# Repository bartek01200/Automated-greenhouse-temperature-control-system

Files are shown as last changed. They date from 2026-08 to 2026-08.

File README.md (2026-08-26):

# Automated-greenhouse-temperature-control-system

An embedded greenhouse monitoring and ventilation system combining a custom PCB, BMP180 environmental sensor, embedded C++ firmware and servo-actuated window mechanism.

The system continuously monitors temperature and atmospheric pressure while allowing the user to set an adjustable 20–35°C temperature threshold using an onboard potentiometer.When the measured temperature exceeds the selected threshold,the controller automatically opens the ventilation window and activates visual and audible warning indicators.

### Front View
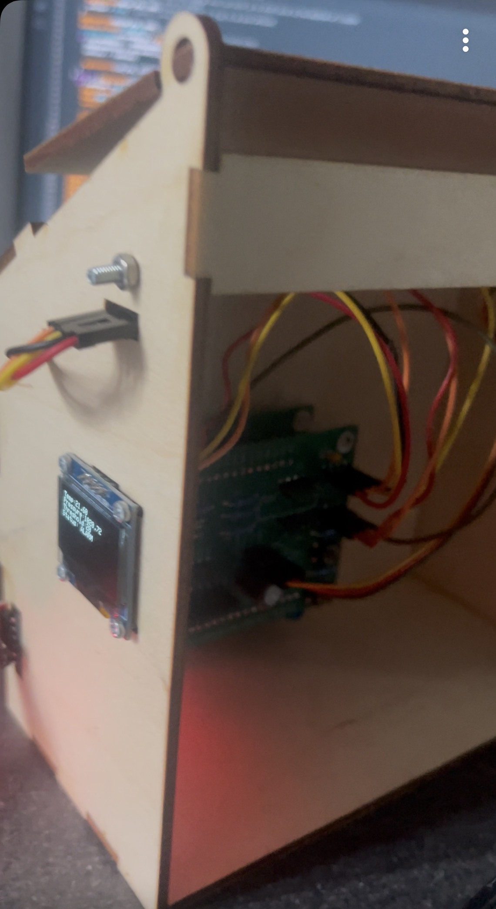
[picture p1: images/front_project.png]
Front Project View


### Side View
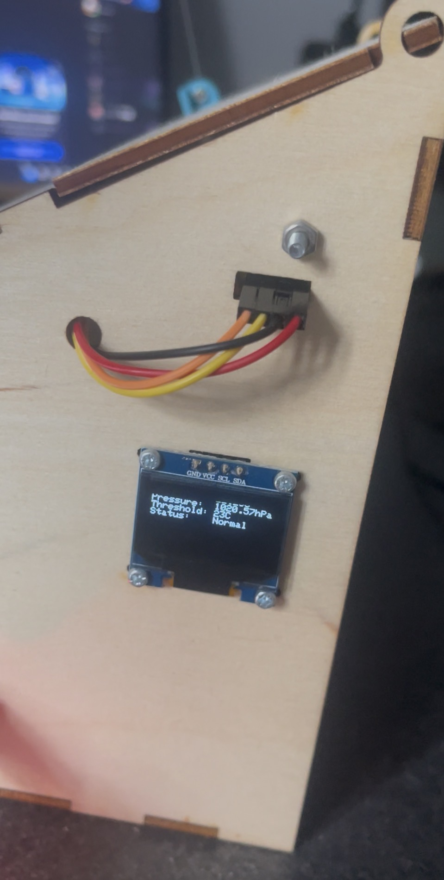
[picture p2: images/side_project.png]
Side View


## CAD Front view
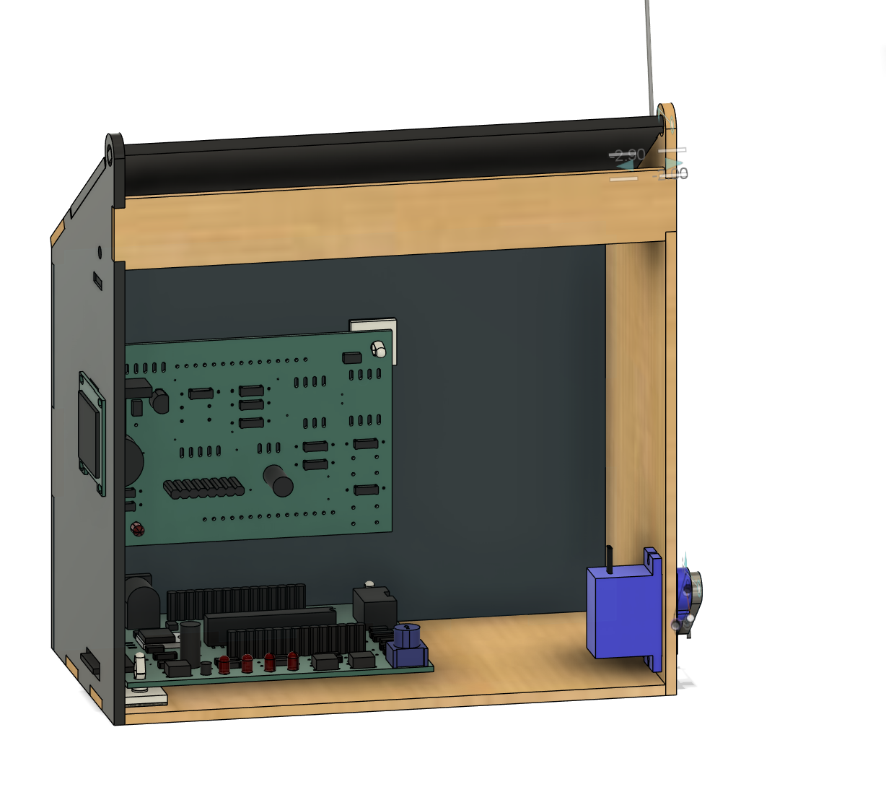
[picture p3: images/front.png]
Front View


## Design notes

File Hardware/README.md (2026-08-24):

## Hardware 

The project used a supplied TSC033 ATmega controller board. I assembled and soldered the controller board, programmed the MCU in C++ using the Arduino framework through the supplied USB programming adapter/interface PCB, and integrated the controller with my custom mating PCB and peripheral hardware.

The custom top board PCB, including the sensor interfaces, potentiometer input, relay driver, protection circuitry, servo interface and status outputs, was designed, assembled and soldered by me before being integrated with the firmware and mechanical system.

### Hardware features

- MCU mating headers for connection to the controller board

- BMP180 temperature and atmospheric pressure sensor interface

- SSD1306 OLED display interface over I²C

- nalogue potentiometer input for adjustable temperature threshold control

- Two push-button inputs for manual open and close override

- SG90 servo interface for ventilation control

- Relay controlled servo power switching

- 2N4401 NPN transistor relay driver

- 1N4004 flyback diode for inductive transient protection

- LED status indicators

- Audible buzzer output

- Local power-supply decoupling capacitors

- External relay output connection

- PCB mounting holes for mechanical integration

## Controller Platform
The system interfaces with a supplied **TSC033 ATmega-based controller board**, which provides the MCU, power regulation, programming interface and I/O connections used by the custom PCB.

The controller board was physically assembled and soldered by me as part of the project before integration with the custom top-board PCB.

Available MCU interfaces used by the system include:

- A0 –Potentiometer input for adjustable temperature threshold.
- A4 / SDA –I²C data connection.
- A5 / SCL –I²C clock connection.
  *Digital inputs -Manual control switches.
- Digital outputs –Status indicators, buzzer, relay and servo control.
- 5 V and GND rails –Power distribution to the custom PCB and peripherals.

The custom PCB was designed to mate with the controller board through the supplied board-to-board connector arrangement.

## Provided and Custom Hardware
Several components were supplied as part of the project platform, including:

- ATmega-based controller board
- I/O daughter board
- SG90 micro servo
- Greenhouse structural frame
- Push rod and associated hardware

These components were integrated with the electronics and mechanical system developed for the project.

My hardware work included:

- Designing the custom mating PCB.
- Designing the supporting sensor, actuator and user-interface circuitry.
- Implementing the relay driver and flyback protection circuit.
- Adding power-supply decoupling.
- Integrating the BMP180 and OLED through I²C.
- Integrating the potentiometer through the MCU ADC.
- Providing interfaces for the servo, buzzer, LEDs and manual controls.
- PCB assembly and soldering.
- System wiring, commissioning and debugging

### Relay Driver Circuit:

The relay is driven using a 2N4401 NPN transistor rather than directly from the MCU output.

The MCU controls the transistor through a base resistor, allowing the transistor to switch the higher relay coil current.

A 1N4004 flyback diode is connected across the relay coil to suppress the inductive voltage spike generated when the relay is switched off.

The relay is used to switch power to the servo motor during movement. Once the required window position has been reached, the firmware disables the relay to remove idle servo power and reduce unnecessary power consumption and servo jitter.

### Potentiometer Interface:

The potentiometer forms an analogue voltage divider between the supply and ground rails.

Its wiper is connected to the MCU's analogue input A0, allowing the firmware to sample its position using the ADC.

The resulting ADC value is mapped in firmware to an adjustable temperature threshold between:
20°C and 35°C

This provides real time hardware adjustment of the ventilation temperature without requiring firmware modification.

### PCB Layout:
The PCB layout integrates the MCU connectors and supporting circuitry onto a single board while providing connections for the sensor, display, servo and user controls.

During layout, component placement was arranged around the required MCU mating headers and mechanical constraints of the greenhouse assembly.

### PCB Assembly:
The PCB was manually assembled and soldered before system commissioning.

Following assembly, continuity and component connections were checked before the board was connected to the MCU and integrated with the complete system.

### Main Components:

- BMP180 - Temperature and atmospheric pressure sensing

- SSD1306 OLED - Real time system information display

- Potentiometer - User adjustable temperature threshold

- SG90 Servo - Greenhouse window actuation

- Relay - Servo power switching

- 2N4401- Relay driver transistor

- 1N4004- Relay flyback protection

- Push Buttons- Manual open/close override

- LEDs- Visual status indication

- Buzzer- Audible over temperature indication

- Decoupling Capacitors- Supply filtering and stability

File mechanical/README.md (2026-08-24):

## Mechanical 

The mechanical ssystem was designed in Autodesk Fusion 360 to support the  electronics and provide a servo actuated ventilation window.

The design integrates the window mechanism, SG90 servo motor which connects to metal rod, metal rod,roof mount,connector between rod and roof mount, environmental sensor and custom PCB into a complete electromechanical assembly.

## Mechanical Assembly
The greenhouse structure consists of several individual components assembled into the final enclosure and ventilation mechanism.

## CAD Design
Main mechanical components:
- Base plate
- Back panel
- Left and right side panels
- Front brace
- Fixed roof section
- Hinged ventilation roof/window
- SG90 servo mounting arrangement
- Push rod
- roof mount
- push rod connector
- Servo rotator/linkage
- PCB  standoff mounts 4x on each corner to help with cooling and preventing shorting
- Sensor mounting provision
- OLED mounting provision

The assembly was designed to support and integrate the custom PCB, MCU daughter board, BMP180 sensor, OLED display and SG90 servo motor.

## Window Mechanism:
The ventilation window is actuated using an SG90 micro servo mounted to the side of the greenhouse structure.

The servo transfers rotational motion through a mechanical linkage consisting of:
Servo → Rotator → Push Rod → Push-Rod Connector → Hinged Window
This converts the rotational movement of the servo horn into controlled movement of the ventilation window.

The firmware commands two calibrated servo positions:
150° — Window closed
90° — Window open

The linkage geometry and servo positions were selected to provide sufficient window movement while remaining within the mechanical limits of the assembly.

## Electronics Integration
The mechanical assembly was designed around the electronic subsystems rather than treating the electronics and enclosure separately.

The Fusion 360 assembly includes representations of:

- Custom controller PCB
- MCU / I/O daughter board
- BMP180 environmental sensor
- SSD1306 OLED display
- SG90 servo motor

PCB support pins and mounting features were incorporated to secure the electronics while maintaining clearance for components, wiring and moving parts.

## Fabrication
The project used a combination of fabricated structural components and custom designed mechanical parts.
- CAD contains the original Fusion 360 mechanical designs
- STL contains exported models for 3D-printed components
- DXF contains profiles used for laser cut components
**DESIGN FILES ARE SHOWN WITHIN MECHANICAL FOLDER**

## Final Assembly
The completed mechanical system integrates the greenhouse structure, ventilation linkage, servo actuator, sensor and electronics into a single working prototype.

The servo driven linkage successfully converts rotational motion into controlled opening and closing of the hinged greenhouse window.

**DISCLAIMER**
Intial design was to have PCB on the back and MCU on floor board as seen in CAD pictures.However whilst assembling together i realised its better to have the pcb on top of the MCU as they need to connect thus i did not want to have cables all over the inisde of the greenhouse.So i connected both PCB ontop of each other as the final product.

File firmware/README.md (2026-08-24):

## Firmware:

The control firmware was written in C++ using the arduino framework and integrates the sensor, user controls, display,alarms and window actuator

### Firmware performs:

-Reads temperature and atmospheric pressure from the BMP180 sensor over I²C

-Samples the onboard potentiometer using the MCU's ADC

-Maps the potentiomter reading to a user adjustable 20 - 35C temperature threshold

-Compared ther measured temperature against the selected threshold to control greenhouse ventilation

-Controls an SG90 servo motor to open and close the window

-Uses a relay to supply powert to the servo only during movement, reducing idle poower consumption and servo jitter

-Provides manual open/close through 2 buttons

-Displays temperature,pressure,threshold and system staus on a 128x64 SSD1306 OLED

-Activates a buzzer and blinking LED during an over temperature condition

-Outputs sensor meassurements over 9600 baud serial interface for debugging or testing

### Control logic: Automated Greenhouse Temperature Control System

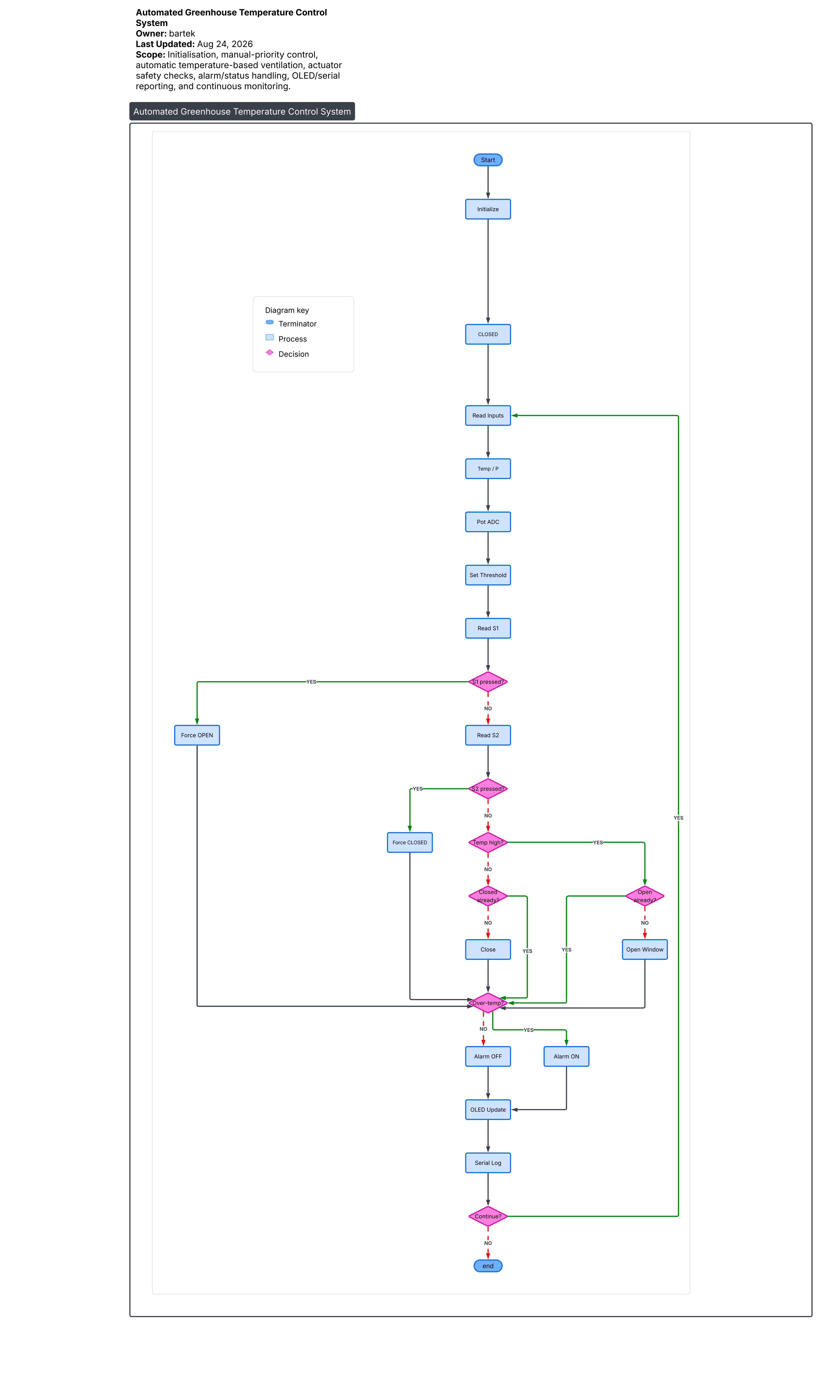
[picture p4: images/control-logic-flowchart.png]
Greenhouse Control Logic Flowchart


contol priority: (emergency) S1 pressed = forces window OPEN S2 pressed = forces window CLOSED no buttons = automatic temperature control

temp above threshold = open vent(window) temp below threshold = close vent

The firmware tracks the current ventilation so the servo only activates when a change in window postion is needed.Servo power is supplied through the relay during movement and diconnected once the required servo position is met.

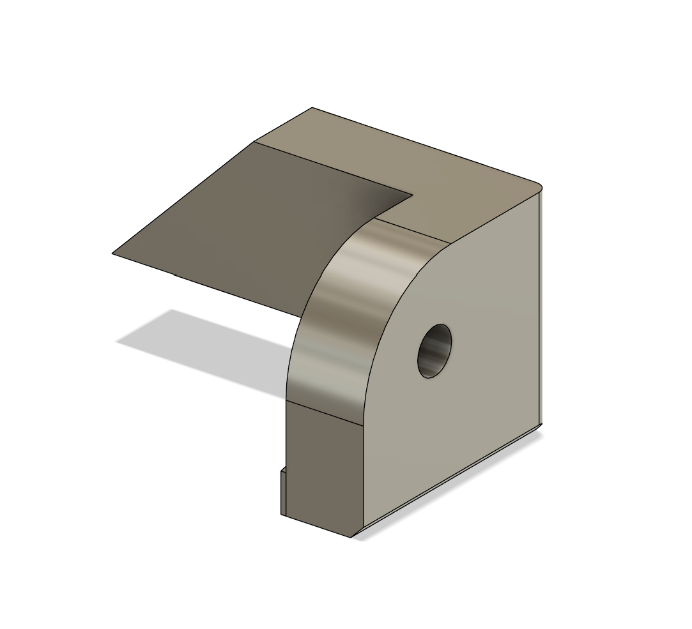
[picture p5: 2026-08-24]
mechanical/CAD/roof_mount.png

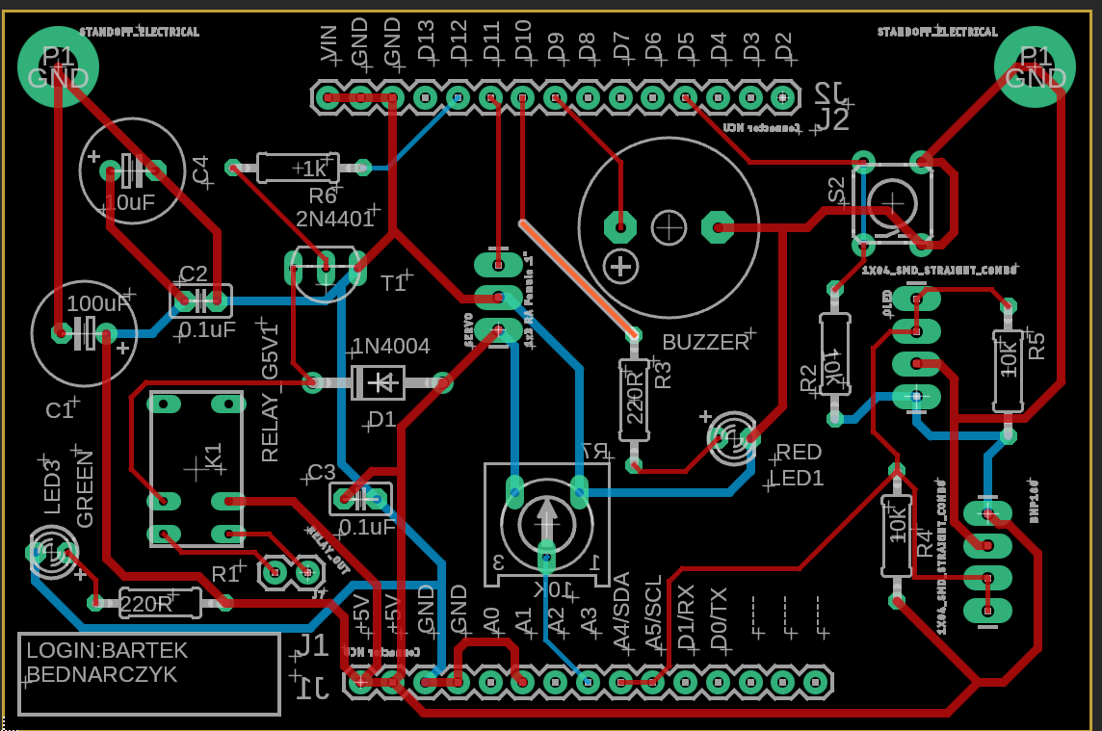
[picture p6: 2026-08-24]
Hardware/PCB/PCB.png

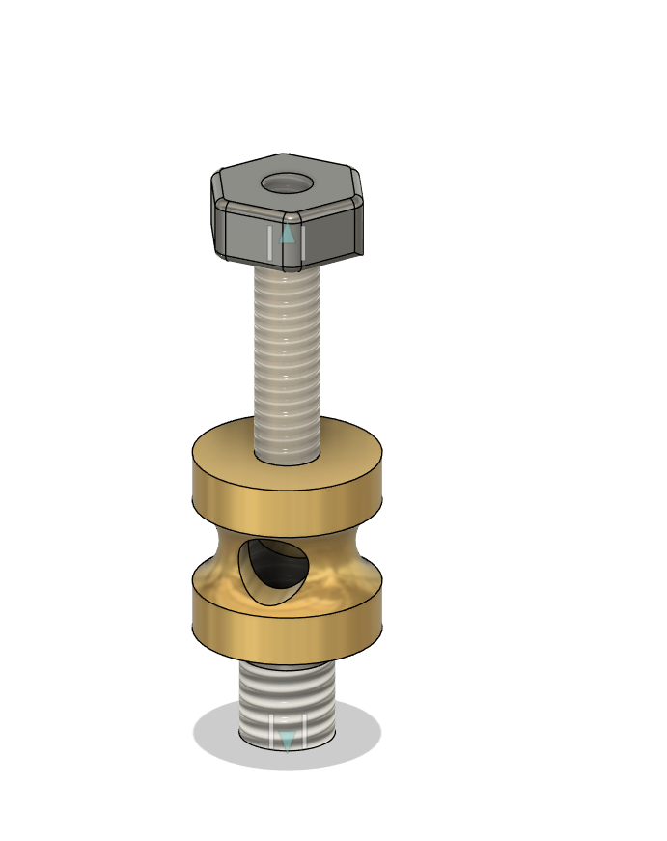
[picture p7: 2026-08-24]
mechanical/CAD/roofmount_connector_PRE-MADE.png

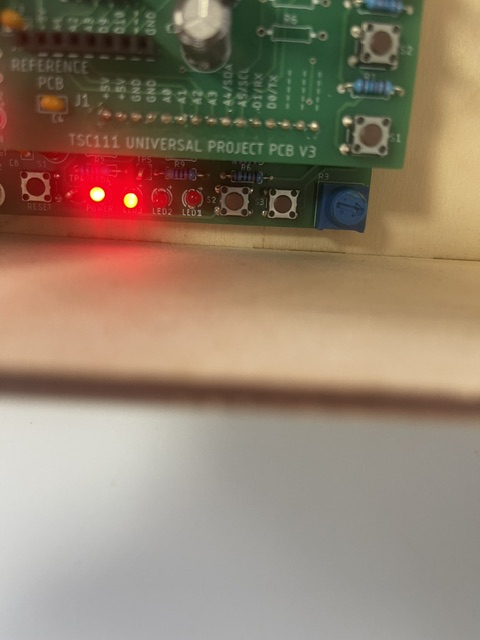
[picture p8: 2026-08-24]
Hardware/PCB/LED.png

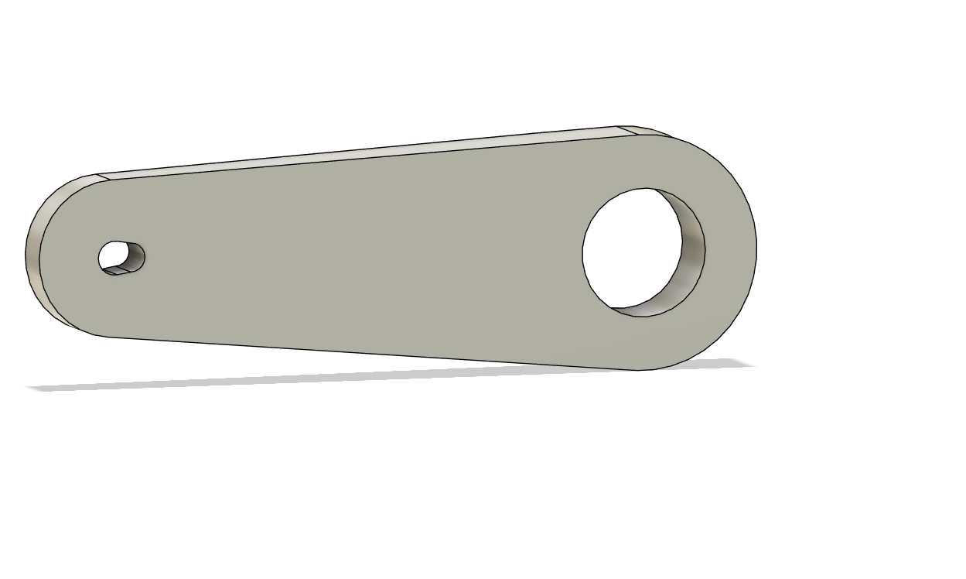
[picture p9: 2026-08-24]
mechanical/CAD/rotator.png

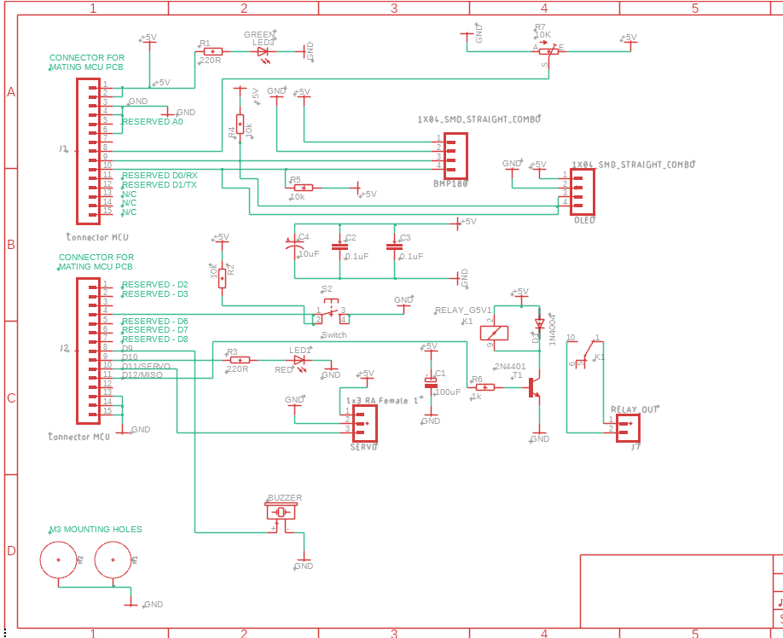
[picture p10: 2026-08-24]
Hardware/Schematic/greenhouse-schematic.png

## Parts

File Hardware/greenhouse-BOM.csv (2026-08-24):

Qty | Value | Device | Package | Parts | Description | MF | MPN | OC_FARNELL | OC_NEWARK | POPULARITY | PROD_ID | SF_ID | SF_SKU | SKU | VALUE
2 | 0.1uF | C2.5/2 | C2.5-2 | C2, C3 | CAPACITOR |  |  |  |  | 1
1 | 100uF | RCL_CPOL-EUE3.5-8 | ELECTROLYTIC_CAP_RCL_E3,5-8 | C1 | POLARIZED CAPACITOR, European symbol
1 | 10K | TRIM_EU-RS3 | RS3 | R7 | POTENTIOMETER |  |  |  |  | 0
3 | 10k | R-EU_0207/10 | 0207/10 | R2, R4, R5 | RESISTOR, European symbol
1 | 10uF | CPOL-USE3.5-8 | E3,5-8 | C4 | POLARIZED CAPACITOR, American symbol
1 | 1N4004 | 1N4004 | DO41-10 | D1 | DIODE |  |  |  |  | 82
2 | 1X04_SMD_STRAIGHT_COMBO | CONN_04LONGPADS | 1X04_LONGPADS | BMP180, OLED | Multi connection point. Often used as Generic Header-pin footprint for 0.1 inch spaced/style header connections |  |  |  |  |  | CONN-08511 | PRT-12638 |  |  | 1X04_SMD_STRAIGHT_COMBO
1 | 1k | R-EU_0207/10 | 0207/10 | R6 | RESISTOR, European symbol
1 |  | CONN_03LONGPADS | 1X03_LONGPADS | SERVO | Multi connection point. Often used as Generic Header-pin footprint for 0.1 inch spaced/style header connections |  |  |  |  |  | CONN-10925 | PRT-08235 | PRT-08433
2 | 220R | R-EU_0207/10 | 0207/10 | R1, R3 | RESISTOR, European symbol
1 | 2N4401 | -NPN-TO92-EBC | TO92-EBC | T1 | NPN Transistror |  |  |  |  | 0
2 | Connector MCU | CONN_15 | 1X15 | J1, J2 | Multi connection point. Often used as Generic Header-pin footprint for 0.1 inch spaced/style header connections
1 | EL311_ATMEGA_INTRO_TSC033_V1_BUZZER_F/CM12P | EL311_ATMEGA_INTRO_TSC033_V1_BUZZER_F/CM12P | EL311_ATMEGA_INTRO_TSC033_V1_BUZZER_F/CM12P | BUZZER | BUZZER Source: Buerklin |  |  | unknown | unknown | 9
1 | GREEN | LED3MM | LED3MM | LED3 | LED
1 | RED | ADAFRUIT_LED3MM | ADAFRUIT_LED3MM | LED1 | LED
1 | RELAY_G5V1 | RELAY_G5V1 | RELAY_G5V1 | K1 | RELAY |  | G5V-1-DC24 | 9949593 | 36M6377 | 0
1 | RELAY_OUT | SPARKFUN-CONNECTORS_CONN_02 | SPARKFUN-CONNECTORS_1X02 | J7 | Multi connection point. Often used as Generic Header-pin footprint for 0.1 inch spaced/style header connections |  |  |  |  |  | CONN-13512 | PRT-09918 | PRT-08432 | PRT-09914
2 | STANDOFF_ELECTRICAL | STANDOFF_ELECTRICAL | STANDOFF-ELECTRICAL | H1, H2 | Stand Off
1 | Switch | EL311-ROBOT_SPARKFUN-ELECTROMECHANICAL_TAC_SWITCHPTH | EL311-ROBOT_SPARKFUN-ELECTROMECHANICAL_TACTILE-PTH | S2 | Momentary Switch

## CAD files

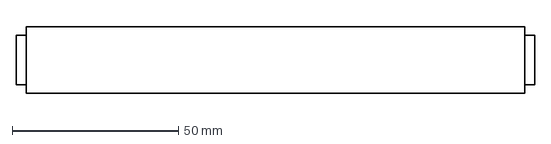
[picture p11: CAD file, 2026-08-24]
mechanical/DXF/mechanics DXF FILE/FRONTBRACE.dxf
156.0 x 20.0 mm

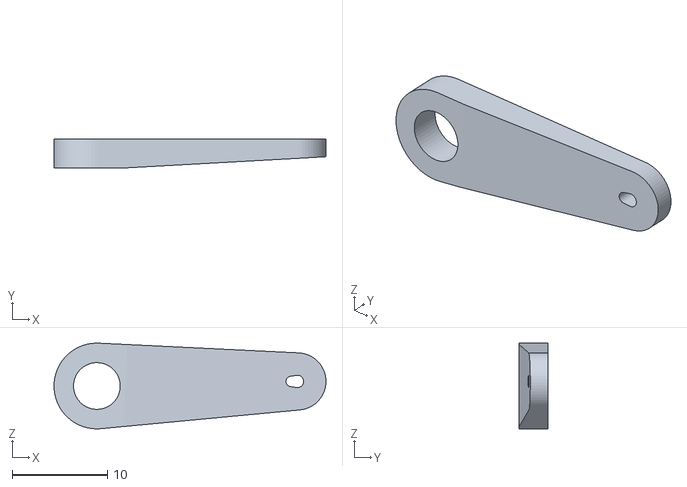
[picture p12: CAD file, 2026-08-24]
mechanical/STL/mechanics STL FILE/ROTATOR.stl
28.5 x 3.00 x 8.99

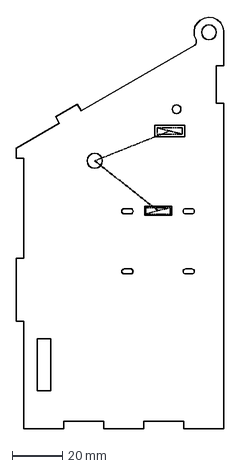
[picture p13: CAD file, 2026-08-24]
mechanical/DXF/mechanics DXF FILE/LEFT_ONLY.dxf
83.0 x 164.8 mm

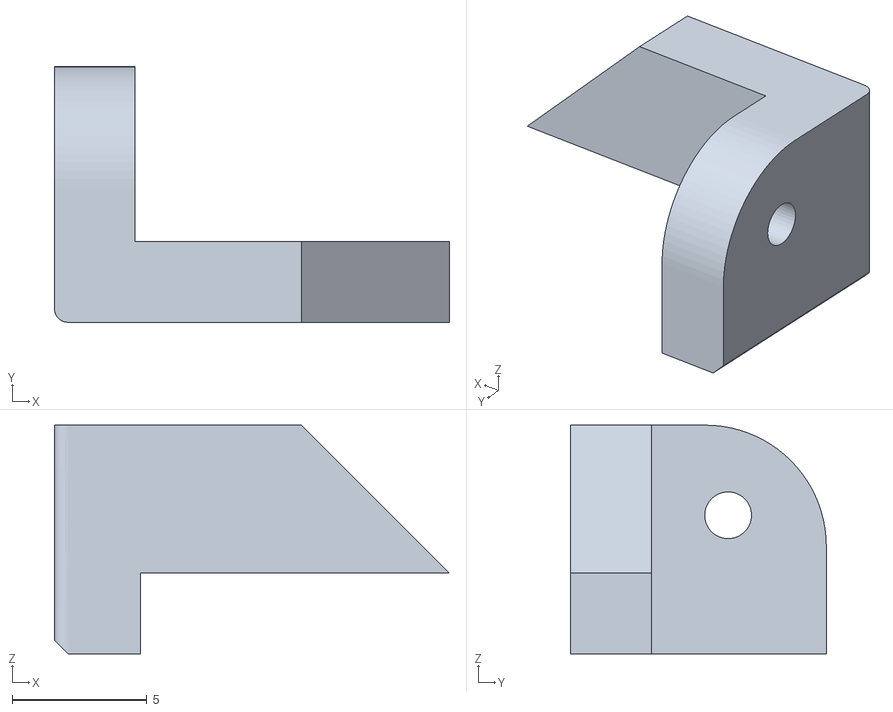
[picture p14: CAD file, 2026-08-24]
mechanical/STL/mechanics STL FILE/MOUNT.stl
14.7 x 9.50 x 8.50

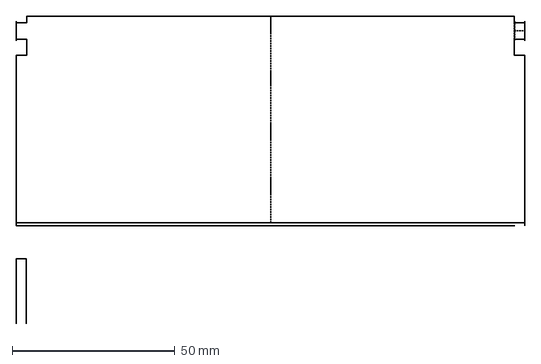
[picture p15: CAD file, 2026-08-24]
mechanical/DXF/mechanics DXF FILE/HINGED_ROOF.dxf
156.0 x 94.4 mm

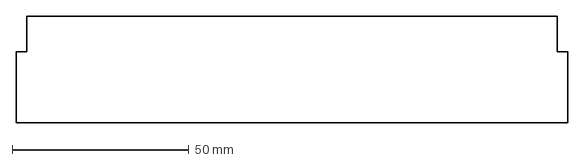
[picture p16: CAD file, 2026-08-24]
mechanical/DXF/mechanics DXF FILE/FIXED ROOF.dxf
156.0 x 30.0 mm

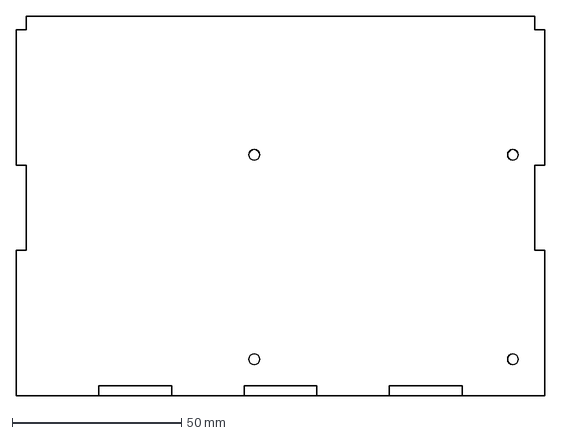
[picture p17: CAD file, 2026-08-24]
mechanical/DXF/mechanics DXF FILE/BACK.dxf
156.0 x 112.1 mm

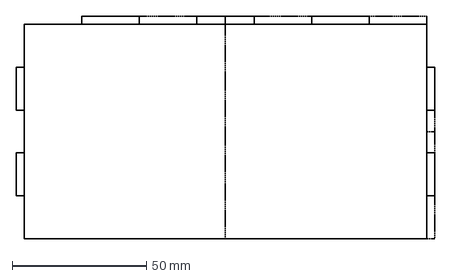
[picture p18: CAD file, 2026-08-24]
mechanical/DXF/mechanics DXF FILE/BASE.dxf
156.0 x 83.0 mm

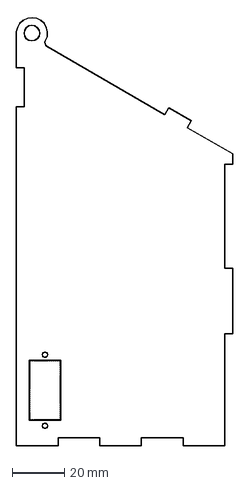
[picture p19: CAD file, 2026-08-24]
mechanical/DXF/mechanics DXF FILE/RIGHT_ONLY.dxf
83.0 x 164.8 mm

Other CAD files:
mechanical/CAD/GREENHOUSE ASSEMBLY ALTERED.f3z
mechanical/CAD/GREENHOUSE NEW VERSION.f3z
mechanical/CAD/greenhouse-assembly.f3d

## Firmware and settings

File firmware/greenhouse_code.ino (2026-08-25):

#include <Wire.h>
#include <Adafruit_GFX.h> //Include Adafruit graphics library for OLED
#include <Adafruit_SSD1306.h>
#include <Adafruit_BMP085.h>
#include <Servo.h>

#define SCREEN_WIDTH 128
#define SCREEN_HEIGHT 64 //OLED display height in pixels
#define OLED_RESET -1

Adafruit_SSD1306 display(SCREEN_WIDTH, SCREEN_HEIGHT, &Wire, OLED_RESET);

Adafruit_BMP085 bmp;
Servo ventServo; //create a servo object to control the opening of it 

//pin assignments
const int SWITCH_S1  = 4;//switch S1 mapped to digital Pin 4
const int SWITCH_S2  = 2;
const int POT_PIN = A0;
const int SERVO_PIN  = 11;
const int BUZZER_PIN = 12;
const int RELAY_PIN  = 13;
const int LED_PIN= 8;
//Servo positions
const int SERVO_CLOSED_ANGLE = 150;// 5 o'clock position (Closed position)
const int SERVO_OPEN_ANGLE = 90;

//Control parameters
const float HYSTERESIS = 0.5;
const long BLINK_INTERVAL = 500;

int threshold = 0;
float currentTemp = 0.0;// Variable to store temperature data
float pressure = 0.0;

bool ventOpen = false;//track state of the ventilation window
bool ledState = false;
unsigned long lastBlinkMillis = 0;

void setup() {
  Serial.begin(9600);//open serial communications at 9600 baud


  pinMode(LED_PIN, OUTPUT);
  pinMode(SWITCH_S1, INPUT_PULLUP);
  pinMode(SWITCH_S2, INPUT_PULLUP); //configure Switch 2 with internal pull up resistor
  pinMode(BUZZER_PIN, OUTPUT);
  pinMode(RELAY_PIN, OUTPUT);//configure Relay pin as a digital output

  digitalWrite(BUZZER_PIN, LOW);
  digitalWrite(LED_PIN, LOW);
  digitalWrite(RELAY_PIN, LOW);// relay OFF until we deliberately pulse it

  //Initialise OLED
  if (!display.begin(SSD1306_SWITCHCAPVCC, 0x3C)) {
    Serial.println("OLED failed");
  }

  display.clearDisplay();
  display.display();

  //Initialise BMP180
  if (!bmp.begin()) {
    Serial.println("BMP180 failed");
  }

  //Initialise servo in closed position
  ventServo.attach(SERVO_PIN);//attach the servo object to its control pin
  digitalWrite(RELAY_PIN,HIGH);//Engage relay to give servo temporary setup power
  delay(100);
  ventServo.write(SERVO_CLOSED_ANGLE);
  delay(600);
  digitalWrite(RELAY_PIN,LOW);
}


void openVent() {
  if (!ventOpen) {
    digitalWrite(RELAY_PIN,HIGH);
    delay(100);
    ventServo.write(SERVO_OPEN_ANGLE);
    delay(600);
    digitalWrite(RELAY_PIN,LOW);
    ventOpen = true;
  }
}


void closeVent() {
  if (ventOpen) {
    digitalWrite(RELAY_PIN,HIGH);
    delay(100);// lets the voltage increase
    ventServo.write(SERVO_CLOSED_ANGLE);
    delay(600);
    digitalWrite(RELAY_PIN,LOW);//turns off power to relay to be more efficent
    ventOpen = false;
  }
}


void loop() {

  currentTemp = bmp.readTemperature();//fetch temperature data from BMP180
  pressure = bmp.readPressure()/100.0F;//fetches  pressure and convert to hPa
  //Read user adjustable temperature threshold
  int potValue = analogRead(POT_PIN);
  threshold = map(potValue, 0, 1023, 20, 35);

  bool manualOpen  = digitalRead(SWITCH_S1) ==LOW;
  bool manualClose = digitalRead(SWITCH_S2) == LOW;
  bool overTemperature = currentTemp > threshold;


  if (manualOpen) {
    openVent();
  }
  else if (manualClose) {
    closeVent();
  }
  else if (!ventOpen && currentTemp>threshold + HYSTERESIS) {//checks if the ventilation window is currently closed
    openVent();
  }
  else if (ventOpen &&currentTemp <threshold - HYSTERESIS) {
    closeVent();
  }

  if (overTemperature) {
    digitalWrite(BUZZER_PIN,HIGH);
    unsigned long currentMillis = millis();

    if (currentMillis -lastBlinkMillis>= BLINK_INTERVAL) {
      lastBlinkMillis =currentMillis;
      ledState = !ledState;
      digitalWrite(LED_PIN,ledState);
    }
  }
  else {
    digitalWrite(BUZZER_PIN,LOW);
    ledState = false;
    digitalWrite(LED_PIN,LOW);
  }


  Serial.print("Temp:");//displays temp
  Serial.println(currentTemp);
  Serial.print("Pressure:");
  Serial.println(pressure);

  Serial.print("Threshold: ");
  Serial.println(threshold);


  display.clearDisplay();//clears oled
  display.setTextSize(1);
  display.setTextColor(WHITE);
  display.setCursor(0, 0);
  display.print("Temp:");
  display.print(currentTemp);
  display.println(" C");
  display.print("Pressure:");
  display.print(pressure);
  display.println(" hPa");
  display.print("Threshold:");
  display.print(threshold);
  display.println(" C");
  display.print("Window: ");
  display.println(ventOpen? "OPEN":"CLOSED");
  display.print("Status:");
  display.println(overTemperature? "ALARM":"NORMAL");
  display.display();
  delay(200);
}
                                   
}

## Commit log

2026-08-24 Implement control logic for window ventilation
    Added control logic for window operation based on temperature thresholds and button inputs. Updated comments for clarity.
2026-08-24 Implement automated temperature control logic
    Added control logic for automated greenhouse temperature management.
2026-08-24 flow chart of control logic
2026-08-24 control logic flow chart
2026-08-24 Rename Blank diagram.png to control-logic-flowchart.png
2026-08-24 Create schematic
2026-08-24 Create pcb
2026-08-24 circuit logic
2026-08-24 flowchart of control logic
2026-08-24 control logic flowchart
2026-08-24 Enhance README with comprehensive hardware documentation
    Expanded the README with detailed hardware features, relay driver circuit explanation, potentiometer interface details, PCB assembly process, and main components list.
2026-08-24 Add PCB layout section to README
    Added PCB layout section detailing component integration and placement considerations.
2026-08-24 Create 3D printed parts
2026-08-24 Create laser-cut parts
2026-08-24 Revise README for mechanical assembly and integration details
    Updated the README to enhance clarity on mechanical assembly and features, including detailed descriptions of components and their integration with electronics.
2026-08-24 cad model
2026-08-24 Clarify PCB mounting structure in README
    Updated PCB mounting structure description for clarity.
2026-08-24 PCB SCHEMATIC
    [TOP_PCB.dbl.sch]
2026-08-24 Update Schematic
2026-08-24 Fix image syntax in Schematic documentation
2026-08-24 DXF files
    [BACK.dxf, BASE.dxf, FIXED ROOF.dxf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]
2026-08-24 f3z files
    [GREENHOUSE ASSEMBLY ALTERED.f3z, GREENHOUSE NEW VERSION.f3z]
